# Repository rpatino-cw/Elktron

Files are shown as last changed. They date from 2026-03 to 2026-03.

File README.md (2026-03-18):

<div align="center">
  Elktron — Robotics for the data center floor
  <h1>Elktron</h1>
  <p><strong>A robotics platform for data center operations.</strong></p>
  <p>Demonstrated through an autonomous escort bot, a robot-arm training pipeline, and a live operations dashboard.</p>
  <p>
    
    
    
    
  </p>
  <p>
    <a href="https://rpatino-cw.github.io/Elktron/"><strong>Live Site</strong></a>
  </p>
</div>

<br/>

## The Problem

Data center technicians spend hours each shift on repetitive physical work — walking alongside vendors, watching them work, manually logging rack interactions, seating optics one-by-one. These tasks are mechanical and tie up skilled engineers who should be troubleshooting, turning up racks, and solving real problems. Elktron automates the floor work so DCTs can focus on what actually moves the needle.

---

## The Live Demo — Escort Bot

<div align="center">
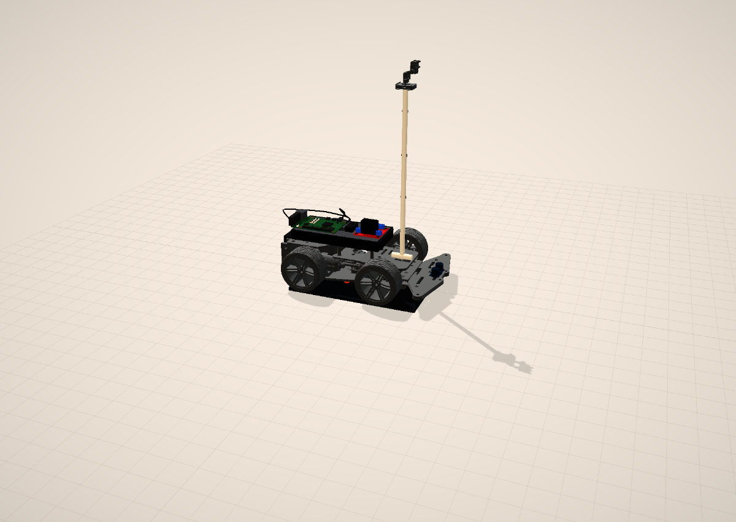
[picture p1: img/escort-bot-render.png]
Escort Bot — fully assembled with mast and pan-tilt camera

</div>

An autonomous 4WD robot that lives in the data hall. When a vendor enters, the bot detects them using real-time person detection, follows them through the aisles at a safe distance, and stops when they stop. If the vendor pauses at a rack, the bot runs an automated camera scan — sweeping bottom to top, capturing the state of every node before and after work is done.

No ROS. No cloud. A Raspberry Pi 5, a camera, and Python.

The tech checks in the vendor, assigns the bot, and goes back to real work.

<code>Raspberry Pi 5 · YOLOv8n · 4WD Chassis · PID Steering · Ultrasonic Obstacle Avoidance</code>

<a href="https://rpatino-cw.github.io/Elktron/escort-bot/assembly.html">

</a>
&nbsp;
<a href="https://rpatino-cw.github.io/Elktron/escort-bot/simulation.html">

</a>

---

## The Platform Extends — SO-101 Robot Arm

A robotic arm trained by demonstration to seat optics into switch ports. A technician shows the arm the task — pick up a transceiver, align it, insert it — and the arm learns to repeat the motion autonomously. No manual programming. You teach by showing.

Built on the HiWonder SO-ARM101 platform using Hugging Face's LeRobot framework. After ~50 demonstrations, the arm trains an ACT policy and runs on its own — same motion, same precision, no fatigue.

<code>SO-ARM101 · LeRobot · ACT Policy · 6-DOF Feetech Servos</code>

<a href="https://rpatino-cw.github.io/Elktron/robotics-site/so101/showcase.html">

</a>

---

## Unified Dashboard

Both robots feed into a single control panel — escort bot position, camera feeds, arm task progress, scan history. A tech sees at a glance what's running, what's done, and what needs attention without walking the floor.

<code>FastAPI · WebSocket · Vanilla JS</code>

---

## Why It's Reproducible

Every component comes with interactive 3D documentation — assembly instructions, wiring diagrams, a full DC floor simulation. The system is packaged not just as a demo, but as something another CoreWeave site could understand and build.

| Demo | What It Shows |
|---|---|
| [**3D Assembly Guide**](https://rpatino-cw.github.io/Elktron/escort-bot/assembly.html) | 15-step escort bot build with animated 3D models |
| [**Interactive Wiring**](https://rpatino-cw.github.io/Elktron/escort-bot/wiring-guide.html) | GPIO pin map — every connection between Pi, motor driver, sensors, and power |
| [**DC Floor Simulation**](https://rpatino-cw.github.io/Elktron/escort-bot/simulation.html) | 10-rack data hall with autonomous bot AI and collision detection |
| [**System Topology**](https://rpatino-cw.github.io/Elktron/robotics-site/topology.html) | How the escort bot, arm, and dashboard connect |

---

## Architecture

```mermaid
graph LR
    A["<b>Escort Bot</b><br/>Pi 5 · YOLOv8n · PID Steering"] -->|WebSocket| C["<b>Elktron Dashboard</b><br/>FastAPI · Vanilla JS"]
    B["<b>SO-101 Arm</b><br/>LeRobot · ACT Policy"] -->|Serial USB| C
    C -->|Live UI| D["Browser<br/>Status · Camera · Scan Logs"]
```

---

## Tech Stack

| Component | Stack |
|---|---|
| **Escort Bot** | Raspberry Pi 5 · YOLOv8n (Ultralytics) · picamera2 · gpiozero · lgpio · PID controller · Python 3.11 |
| **SO-101 Arm** | LeRobot (HuggingFace) · ACT policy · Feetech serial bus · PyTorch · Python |
| **Dashboard** | FastAPI · WebSocket · Vanilla JS · CSS Grid |

---

## Quick Start

**Escort Bot** (on Raspberry Pi 5 — Bookworm Lite 64-bit):
```bash
cd escort-bot && chmod +x install.sh && ./install.sh
python3 main.py              # Full escort + scan mode
python3 main.py --simulate   # Test without hardware
```

**SO-101 Arm** (Mac/Linux with CUDA, MPS, or CPU):
```bash
cd robotics-site/so101 && chmod +x install.sh && ./install.sh
python record.py     # Record demos via teleoperation
python train.py      # Train ACT policy
python deploy.py     # Deploy autonomous
```

---

## Build Progress

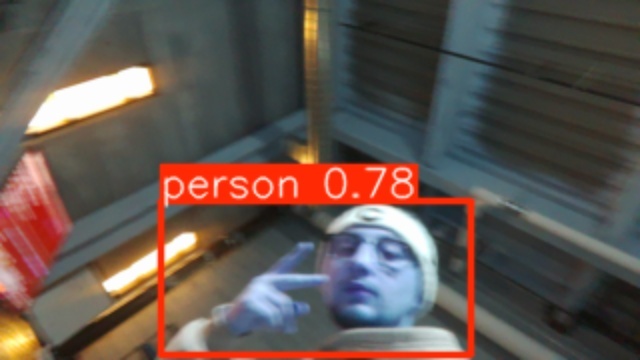
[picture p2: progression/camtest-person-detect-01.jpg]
YOLOv8n person detection running on Pi 5


> *YOLOv8n person detection confirmed at 78% confidence on the DC floor — March 16, 2026*

| Milestone | Status |
|---|---|
| Chassis assembled (LK-COKOINO 4WD) | Done |
| L298N motor driver wired to Pi 5 GPIO | Done |
| Arducam IMX708 wide-angle camera via CSI | Done |
| YOLOv8n person detection on Pi 5 | **Working** |
| Claude Code running on Pi 5 | Done |
| Motor control + PID tuning | Next |
| Full person-following integration | Next |
| SO-101 arm assembly + training | Next |

---

<details>
<summary><strong>Hardware Cost — $430 total</strong></summary>
<br/>

| Item | Cost | Status |
|---|---|---|
| LK-COKOINO 4WD Chassis | $25 | Assembled |
| L298N Motor Driver | $7 | Wired |
| Arducam IMX708 Wide-Angle | $60 | Connected |
| Arducam Pan-Tilt Platform | $27 | In hand |
| Raspberry Pi 5 (4GB) + Active Cooler | $70 | Running |
| HC-SR04 Ultrasonic Sensor | $9 | In hand |
| HiWonder SO-ARM101 | $270 | Ordered |
| Batteries + USB-C Power Bank | $48 | In hand |
| PVC Mast + Fittings | $15 | In hand |
| **Total** | **~$430** | |

</details>

<details>
<summary><strong>Repo Structure</strong></summary>
<br/>

```
hackathon/
├── escort-bot/              # Escort bot — brain, wiring, setup, 3D pages
│   ├── main.py              # Robot brain (373 lines — FOLLOW / SCAN / IDLE)
│   ├── pan_tilt.py           # Pan-tilt servo controller
│   ├── pid.py                # PID controller for steering
│   ├── assembly.html         # 3D assembly guide (Three.js)
│   ├── simulation.html       # DC floor simulation
│   ├── wiring-guide.html     # Interactive 3D wiring
│   ├── tests/                # Hardware test scripts
│   └── tools/                # Label printer, PDF generators
├── robotics-site/            # SO-101 arm — landing page + code
│   └── so101/                # record.py, train.py, deploy.py
├── elktron-app/              # Dashboard — FastAPI + WebSocket UI
│   └── api/server.py
├── glb/                      # 3D models (Meshy AI generated)
├── progression/              # Build progress photos
├── docs/                     # Checklists, parts list, team, philosophy
└── PROGRESS.md               # Single source of truth
```

</details>

<details>
<summary><strong>Demo Story (2:30)</strong></summary>
<br/>

1. **The Problem** (25s) — DC floor, repetitive tasks, skilled techs on autopilot
2. **Escort Bot** (75s) — Bot follows vendor through aisle, stops at rack, scans. Dashboard shows live tracking. "No ROS. No cloud. A Pi, a camera, and Python."
3. **Robot Arm** (35s) — Platform extends to optic seating. Trained by demonstration, runs autonomously. "You teach by showing."
4. **Close** (15s) — Dashboard unifies both systems. "Elktron — the data hall assistant. More. Better. Faster."

</details>

---

## Team

| Name | Role |
|---|---|
| **Romeo Patino** | Architecture, software, integration |
| **Alex Murillo** | Escort bot hardware, chassis, field testing |
| **Joshua Tapia** | SO-101 arm — CV, inverse kinematics, ACT training |
| **Parth Patel** | Dashboard backend, data integration |
| **Talha Shakil** | Demo video, pitch deck, media |
| **Raphael Rodea** | Build crew, logistics, demo day ops |

---

<div align="center">
<sub>Built in 7 days with $430 for CoreWeave "More. Better. Faster." 2026</sub>
<br/>
<sub><a href="docs/">Full documentation</a> · <a href="PROGRESS.md">Build progress</a> · <a href="https://rpatino-cw.github.io/Elktron/">Project Hub</a></sub>
</div>

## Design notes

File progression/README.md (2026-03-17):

# Progression — Build Evidence

Photos and screenshots documenting the Elktron escort bot build process at the DC floor.

---

## 2026-03-16 — Full Hardware Assembly + Person Detection Working

Major milestone: chassis assembled, L298N wired to Pi 5 GPIO, Arducam IMX708 connected via CSI ribbon, and **YOLOv8n person detection confirmed working on the DC floor** at 78% confidence. Claude Code installed directly on the Pi for on-device AI development.

### Hardware Assembly Photos

| File | What |
|---|---|
| `pi5-active-cooler-dc.jpg` | Pi 5 in red case with active cooler, powered at DC workbench (Cisco switch visible) |
| `pi5-camera-ribbon.jpg` | Pi 5 close-up showing CSI ribbon cable ("Standard - Mini 200mm") to Arducam IMX708 |
| `pi5-camera-dc-floor.jpg` | Pi 5 with camera connected, Cisco equipment in background |
| `chassis-wiring-overview.jpg` | Full bot: Pi 5 + LK-COKOINO 4WD chassis + L298N motor driver, all wired |
| `chassis-l298n-full.jpg` | Overhead view — chassis with L298N and motor wiring visible |
| `l298n-wiring-closeup.jpg` | L298N motor driver close-up — blue GPIO wires + red power to motors |
| `l298n-gpio-wires.jpg` | L298N with GPIO control wires (blue/green/black) and motor power (red) |
| `motor-wiring-detail.jpg` | Motor wiring detail — labeled motor connectors, L298N output terminals |

### Person Detection Test (on Pi 5 at DC)

| File | What |
|---|---|
| `camtest-person-detect-01.jpg` | Detection output — "person 0.78" bounding box on camera frame |
| `camtest-person-detect-03.jpg` | Second detection frame — same confidence, different pose |
| `camtest_01-05.jpg` | All 5 test frames with detection bounding boxes |
| `yolov8n-terminal-output.jpg` | Terminal: YOLOv8n loading, 5/5 frames captured, all detecting 1 person |
| `scp-transfer-pi.jpg` | SCP transfer of camtest images from Pi (elktron@192.168.3.57) to Mac |

### Technical Details
- **Model:** YOLOv8n (ultralytics)
- **Camera:** Arducam IMX708 wide-angle (libcamera v0.7.0+rpt20260205)
- **Resolution:** 640x360 sRGB + 1536x864 RAW
- **Confidence:** 0.78 (person class)
- **Pi hostname:** elktron@192.168.3.57
- **Location:** CoreWeave EVI01 DC floor
- **Claude Code:** Installed on Pi — on-device AI development confirmed
- **Chassis:** LK-COKOINO 4WD with yellow-tape motor labels (FR, FL, RR, RL)
- **Motor driver:** L298N (WWZMDiB) — GPIO control wires (blue) + motor power (red)
- **Power:** USB-C power bank visible in assembly photos

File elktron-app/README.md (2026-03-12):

# Elktron Dashboard

Real-time operations dashboard for the Elktron hackathon project — two DC floor robots controlled and monitored from a single interface.

## The Problem

DCTs manage robot arms and escort bots manually. There's no unified view of what the arm is doing, what the escort bot scanned, or whether a vendor touched something they shouldn't have. This dashboard is the control center.

## What It Does

- **Live arm status** — see joint angles, gripper state, and current task in real time
- **Escort monitoring** — watch the bot escort a vendor, scan a rack, and flag unauthorized contact
- **Scan history** — every vendor escort produces a JSON report. Browse, filter, drill in.
- **Training controls** — start/stop teleoperation recording, kick off cloud training, download models
- **Camera feeds** — live USB webcam streams from the arm wrist and escort bot

## Demo Story

1. **Arm demo** — open dashboard, show arm status "READY". Start teleoperation. Move arm to pick optic. Show joint angles updating live. Stop recording. Kick off training.
2. **Escort demo** — vendor arrives. Dashboard shows "Escorting to CAB-B3". Bot arrives, baseline scan runs. Vendor works on RU-24. Dashboard shows live node status. RU-25 gets a brief contact — amber alert, then clears. Work completes. Scan report saved.
3. **Review demo** — open scan log. Show 3 past scans: 2 clean, 1 flagged. Drill into the flagged one — unauthorized contact on RU-19 that didn't resolve.

## Tech Stack

- **Frontend:** HTML + vanilla JS + CSS Grid. WebSocket for live data.
- **Backend:** Python FastAPI. WebSocket bridge to hardware.
- **Hardware:** LeRobot (arm), ROS2 or GPIO (escort bot), USB webcams.

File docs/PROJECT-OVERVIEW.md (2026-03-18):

# Elktron — Project Overview

## What It Is

Elktron is a robotics platform for the data center floor. It automates repetitive physical work — escorting vendors, scanning racks, seating optics — so DCTs can spend their time on troubleshooting, rack turn-ups, and the problems that actually need a human.

The live proof point is the **Escort Bot**: an autonomous robot that detects a person, follows them through the data hall, and scans racks when they stop. The platform extends to a **robot arm** that learns optic seating by demonstration, and a **dashboard** that unifies both systems with live telemetry and control.

## The Problem

At a site like EVI01, technicians spend hours each shift on autopilot work:

- **Vendor escorts** — every visit requires a tech to physically shadow the vendor, 30 minutes to 2 hours each time
- **Optic seating** — inserting transceivers one by one, 5-10 minutes per module, hundreds of ports per rack turn-up
- **Rack inspections** — manual visual checks that could be captured and logged automatically

These tasks don't require engineering skill. They require presence. Elktron provides that presence.

## The Escort Bot

An autonomous 4WD robot that lives in the data hall. When a vendor enters, the bot detects them using real-time person detection (YOLOv8n on a Raspberry Pi 5), follows them through the aisles at a safe distance, and responds to their movement:

- **FOLLOW mode** — tracks the person, maintains target distance using dual PID controllers, steers using differential (tank-style) drive
- **SCAN mode** — when the person stops at a rack for ~3 seconds, the bot assumes work is happening and runs an automated camera sweep, capturing the state of every node from bottom to top
- **IDLE mode** — robot waits patiently until a person reappears

An ultrasonic sensor provides obstacle avoidance at 30cm, because a robot blindly following someone into a rack is how you create an incident report.

The tech checks in the vendor, assigns the bot, and goes back to real work.

**Stack:** Raspberry Pi 5, Arducam IMX708 wide-angle camera, LK-COKOINO 4WD chassis, L298N motor driver, HC-SR04 ultrasonic sensor, gpiozero + Python. No ROS. No cloud.

## The SO-101 Robot Arm

A robotic arm trained by demonstration to seat fiber optic transceivers into switch ports. A technician shows the arm the task — pick up a transceiver, align it, insert it — and the arm learns to repeat the motion autonomously. No manual programming. You teach by showing.

Built on the HiWonder SO-ARM101 (6-DOF, Feetech servos) using Hugging Face's LeRobot framework. After ~50 demonstrations recorded via leader-follower teleoperation, the system trains an ACT (Action Chunking Transformers) policy that generalizes the motion.

The arm represents where the platform goes next — every repetitive physical task on the DC floor is a candidate for this approach.

## The Dashboard

A unified control panel that ties the system together. Five panels: escort bot position and camera feed, arm task progress and joint angles, scan history with before/after images, training metrics, and system health.

Built on FastAPI with WebSocket for real-time telemetry. Designed with mock-data fallback so the dashboard demonstrates the full experience even when hardware isn't connected, then swaps to real data seamlessly when it is.

## Why It's Reproducible

Every component comes with interactive 3D documentation — step-by-step assembly instructions, GPIO wiring diagrams, and a full DC floor simulation. The system is packaged not just as a demo, but as something another CoreWeave site could understand and build.

Key resources:
- **3D Assembly Guide** — 15-step escort bot build with animated Three.js models
- **Interactive Wiring** — every connection between the Pi, motor driver, sensors, and power
- **DC Floor Simulation** — 10-rack data hall with autonomous bot AI
- **System Topology** — how all components connect

## The Stack

| Layer | Technology |
|---|---|
| Compute | Raspberry Pi 5 (4GB, Bookworm 64-bit) |
| Vision | YOLOv8n (Ultralytics), Arducam IMX708 via libcamera |
| Motor control | gpiozero + L298N via GPIO |
| Steering | Custom dual PID (lateral centering + distance tracking) |
| Arm framework | LeRobot (Hugging Face) + ACT policy |
| Arm hardware | HiWonder SO-ARM101, Feetech STS3215 servos |
| Backend | FastAPI + WebSocket + Pydantic |
| Frontend | Vanilla JS — no frameworks |
| 3D documentation | Three.js (v0.162.0–v0.170.0) |
| Remote access | Tailscale |
| On-device dev | Claude Code running directly on the Pi |

## The Team

Six CoreWeave DCTs from Elk Grove:

| Name | Role |
|---|---|
| **Romeo Patino** | Lead — architecture, software, integration, daily comms |
| **Joshua Tapia** | SO-101 arm — assembly, calibration, ACT training |
| **Alex Murillo** | Escort bot hardware — chassis, wiring, field testing |
| **Parth Patel** | Dashboard backend — FastAPI, data integration |
| **Talha Shakil** | Media — demo video, pitch deck, logo |
| **Raphael Rodea** | Build crew — assembly, labels, logistics, demo day ops |

## The Pitch (One Paragraph)

Elktron is the data hall assistant. An autonomous escort bot follows vendors through the DC, scans racks when they stop, and feeds everything to a live dashboard. The platform extends to a robot arm that learns optic seating by demonstration — same dashboard, same telemetry, same unified control. Every component is documented with interactive 3D guides so another site can reproduce it. Built in 7 days by DCTs, for DCTs, with $430 in off-the-shelf parts. Elktron doesn't replace technicians. It gives them back their time.

## Budget

Total: **~$430** for both robots, all parts, off-the-shelf. No custom fabrication.

---

*CoreWeave "More. Better. Faster." Hackathon — March 23–25, 2026 · Demo Day: March 26*
*Track: Build with Velocity*

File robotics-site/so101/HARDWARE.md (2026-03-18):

# Elktron SO-101 — Hardware Guide

## What to Buy

### Option A: HiWonder Kit (easiest)
| Item | Price | Link |
|---|---|---|
| SO-ARM101 DIY Kit (both arms, all servos, boards, power, clamps) | $270 | [hiwonder.com/products/lerobot-so-101](https://www.hiwonder.com/products/lerobot-so-101) |
| USB webcam (1080p) | $20-30 | Any OpenCV-compatible |
| **Total** | **~$300** | |

### Option B: Seeed Studio + 3D Print (cheaper)
| Item | Price |
|---|---|
| Servo motor kit (12x STS3215 servos + boards) | $220 |
| 3D-printed parts (order from JLCPCB/PCBWay or self-print) | $35 |
| USB webcam | $20-30 |
| **Total** | **~$275** | |

### Already Have
- Raspberry Pi 5 (or laptop for training)
- USB-C cables (2x, included in kit)

## Kit Contents (HiWonder DIY)
- 1x Follower arm: 6x HX-30HM bus servos (STS3215, 30kg.cm torque)
- 1x Leader arm: 6x HX-10HM bus servos (STS3215, lighter gearing)
- 2x BusLinker V3.0 servo controller boards
- 1x 12V 5A power supply (follower)
- 1x 5V power supply (leader)
- 4x table clamps
- All 3D-printed structural parts
- Screws, cables, assembly tools

## Assembly Notes
- DIY kit: ~2-3 hours to assemble both arms
- Follow HiWonder's assembly video or [TheRobotStudio GitHub](https://github.com/TheRobotStudio/SO-ARM100) for STLs and build guide
- Clamp both arms to the same table, ~30cm apart
- Camera mounts above or to the side of the follower workspace

## Connections

```
Laptop/Pi 5
  ├── USB-C → BusLinker (Leader arm)
  ├── USB-C → BusLinker (Follower arm)
  └── USB   → Webcam

12V 5A PSU → Follower arm power
5V PSU     → Leader arm power
```

## Compute Options for Training

| Machine | Device flag | Training time (50 episodes) |
|---|---|---|
| Mac M1/M2/M3 | `--device mps` | ~2-4 hours |
| NVIDIA GPU (RTX 3060+) | `--device cuda` | ~1-2 hours |
| Google Colab (free T4) | `--device cuda` | ~3-5 hours |
| Raspberry Pi 5 (CPU) | `--device cpu` | Not recommended for training |

**Hackathon strategy:** Record on Pi/laptop → train on Mac or Colab → deploy on Pi.

## Demo Day Setup

For the Demo Day (March 26) demo, you need:
1. Follower arm clamped to table
2. Optic + transceiver cage in workspace
3. Pi 5 or laptop running `deploy.py`
4. Camera showing the arm's view on a monitor (impressive for audience)

Keep the leader arm connected but out of the way — useful for live teleoperation fallback if the trained policy struggles.

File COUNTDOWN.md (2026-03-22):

# Elktron — Countdown to Demo Day

**Last updated:** 2026-03-21 (update every morning)

---

## Hard Rules

1. **Escort bot (RC) done by Monday 3/24.** No exceptions. This is the star of the demo.
2. **ARM GO/NO-GO: Monday 3/24 end of day.** If it's not assembled, calibrated, and running a basic teleop — cut it from the demo. One perfect robot > two broken robots.
3. **Feature freeze: Tuesday 3/25 noon.** After that, only bug fixes, video recording, and polish.
4. **Romeo does not push code while Josh/Parth are working onsite.** They own the repo during their sessions.

---

## Day-by-Day

### Friday 3/21 — Integration Sprint

| Task | Owner | Status |
|---|---|---|
| Pull latest repo on Pi | Josh | [x] Done |
| Dashboard running on Josh's laptop | Josh, Parth | [ ] |
| Set Pi IP in `escort.py` line 36, test connectivity | Josh | [ ] |
| Camera feed streaming Pi → dashboard | Josh | [ ] |
| Xbox controller teleoperation — bot drives | Josh | [ ] |
| YOLOv8n detection running on Pi camera | Josh, Parth | [ ] |
| Fix L298N 5V logic pin if not done | Josh, Parth | [ ] |
| Demo script review (remote) | Romeo | [ ] |
| Pitch deck polish (remote) | Romeo | [ ] |

**End-of-day check:** Can the bot drive via controller and stream camera to dashboard?

---

### Saturday 3/22 — Arm Print + Bot Tuning

| Task | Owner | Status |
|---|---|---|
| 3D print SO-101 arm parts (overnight print OK) | Josh | [ ] |
| PID tuning — smoother person following | Josh, Parth | [ ] |
| Ultrasonic sensor wired + tested | Josh, Parth | [ ] |
| PVC mast + camera elevation mounted | Onsite crew | [ ] |
| Wire cleanup — velcro, zip ties, clean routing | Onsite crew | [ ] |
| Dashboard polish — Drive & Detection panel | Romeo (remote) | [ ] |
| Repo README cleanup for judges | Romeo | [ ] |

**End-of-day check:** Bot follows a person smoothly. Arm parts printing.

---

### Sunday 3/23 — Hackathon Day 1: Bot Complete + Arm Assembly

| Task | Owner | Status |
|---|---|---|
| Escort bot end-to-end: follow + scan + dashboard | Josh, Parth | [ ] |
| Record phone video of bot following person | Anyone onsite | [ ] |
| Assemble SO-101 arm (3D-printed parts ready) | Josh | [ ] |
| Install LeRobot, calibrate servos | Josh | [ ] |
| First arm teleop test | Josh | [ ] |
| Coordinate with Talha on filming plan | Romeo | [ ] |

**End-of-day check:** Bot demo-ready. Arm assembled and servos responding.

---

### Monday 3/24 — Hackathon Day 2: ARM GO/NO-GO

| Task | Owner | Status |
|---|---|---|
| Arm basic teleop working? | Josh | [ ] |
| **GO/NO-GO DECISION (end of day):** | Team | [ ] |
| → GO: Record 50 optic seating demos, start ACT training | Josh | [ ] |
| → NO-GO: Cut arm from demo, double down on escort bot | Team | [ ] |
| Escort bot floor test — real DC aisle | Onsite crew | [ ] |
| Escort bot scan mode — camera sweeps rack | Onsite crew | [ ] |
| Dashboard with live data — ready for screen recording | Josh | [ ] |
| B-roll filming — bot on floor, wiring, Pi boot | Talha, Raphael | [ ] |

**End-of-day check:** Arm decision locked. Escort bot runs clean on DC floor.

---

### Tuesday 3/25 — Hackathon Day 3: FEATURE FREEZE + VIDEO

**NOON: FEATURE FREEZE. No new code after this.**

| Task | Owner | Status |
|---|---|---|
| Morning: final bug fixes only | Josh, Parth | [ ] |
| NOON: Feature freeze — lock it down | Team | [ ] |
| Record demo video (2:30 target) | Talha + team | [ ] |
| Screen-record dashboard walkthrough | Romeo or Josh | [ ] |
| Record voiceover (separate track) | Romeo | [ ] |
| Edit video — footage + VO + music | Talha | [ ] |
| If arm GO: record arm demo footage | Josh | [ ] |
| Slides/pitch deck finalized | Romeo, Talha | [ ] |
| GitHub repo — clean README, screenshots, links | Romeo | [ ] |
| Submit video + repo + slides | Talha | [ ] |

**End-of-day check:** Video submitted. Repo pushed. Slides done.

---

### Wednesday 3/26 — DEMO DAY (11am-2pm PT / 2pm-5pm ET)

| Task | Owner | Time |
|---|---|---|
| Pack hardware — bot, arm (if GO), power banks, cables, laptop | Raphael | Morning |
| Set up demo table — bot on display, dashboard on screen | Team | 10:30am PT |
| Test live demo — bot drives, dashboard streams | Josh | 10:45am PT |
| Charge all batteries | Raphael | Night before |
| Presentations begin | Team | 11:00am PT |
| Raphael plays "vendor" during live demo | Raphael | During demo |

---

## Talha's Deliverables — Media & Presentation Timeline

| Deadline | Deliverable | Notes |
|---|---|---|
| **Sun 3/23** | Filming plan finalized | Coordinate with Romeo on shot list (`docs/DEMO-SCRIPT.md`) |
| **Mon 3/24** | B-roll filmed | Bot on DC floor, wiring close-ups, Pi boot, terminal output, team working |
| **Mon 3/24 EOD** | Logo + team signage ready | Printed for demo table |
| **Tue 3/25 morning** | All live robot footage filmed | Bot following person, scan mode, arm demo (if GO) |
| **Tue 3/25 noon** | Screen recordings done | Dashboard walkthrough, training pipeline (if arm GO) |
| **Tue 3/25 afternoon** | Voiceover recorded | Romeo records VO, Talha receives audio track |
| **Tue 3/25 evening** | Video edited + exported | 2:30 target, footage + VO + music layered |
| **Tue 3/25 night** | Slides finalized | With Romeo — 5-7 slides max |
| **Tue 3/25 EOD** | **SUBMIT: video + repo + slides** | Final deliverable — non-negotiable deadline |

**Talha needs from the team:**
- Shot list approval by Sunday (Romeo)
- Working robot on DC floor by Monday (Josh)
- Dashboard running live by Monday (Josh)
- Voiceover audio by Tuesday noon (Romeo)
- Arm GO/NO-GO by Monday EOD (determines what to film Tuesday)

---

## Giving Talha Filmable Moments

Talha can't edit what doesn't exist. The team's #1 job Monday is creating footage, not writing code.

**What Talha needs filmed (and who makes it happen):**

| Footage | Who Sets It Up | When | Notes |
|---|---|---|---|
| Bot following a person through DC aisle (wide shot) | Josh drives bot, Raphael walks as "vendor" | Mon 3/24 | THE hero shot. Get 3-4 takes minimum. |
| Bot stop/start behavior — vendor stops, bot stops | Same setup | Mon 3/24 | Shows intelligence, not just driving |
| Bot scan mode — camera sweeps rack | Josh triggers scan | Mon 3/24 | Slow, dramatic tilt. Talha films from side. |
| Close-up: Pi 5 + camera on mast, chassis rolling | Anyone | Mon 3/24 | B-roll. Show the hardware. |
| Dashboard with live data on laptop screen | Josh has dashboard running | Mon 3/24 | Screen-record AND film the laptop from over-shoulder |
| Arm optic seating (if GO) | Josh demos arm | Tue 3/25 morning | Even 1 successful grab is enough |
| Arm training — leader-follower teleop | Josh | Tue 3/25 morning | Shows "teach by demonstration" |
| Team working — wiring, terminal, debugging | Anyone | Mon 3/24 | Candid B-roll. Shows builder energy. |
| DC environment — racks, aisles, cables | Anyone with phone | Mon 3/24 | Sets the scene. 5-10 seconds is enough. |
| Pi boot sequence — terminal scrolling | Anyone | Anytime | Cool visual for transitions |

**How to make this happen:**
1. **Sunday:** Romeo coordinates with Talha on shot list above. Talha confirms he has a phone/camera ready.
2. **Monday morning:** Josh gets bot driving + dashboard live. This is Talha's filming window.
3. **Monday midday:** Talha films all bot footage (30-45 min dedicated filming session). Josh and Raphael support.
4. **Monday afternoon:** Talha films B-roll (team working, DC environment, hardware close-ups).
5. **Tuesday morning:** If arm is GO, Talha films arm footage. If NO-GO, skip — Talha starts editing.
6. **Tuesday noon:** Romeo records voiceover. Sends audio to Talha.
7. **Tuesday afternoon-evening:** Talha edits. Team reviews. Final export.

**Rule:** Monday is filming day, not coding day. If something isn't working by Monday morning, don't spend all day debugging — film what IS working and move on.

---

## Fallback: Single-Robot Demo (if arm is cut)

The demo becomes 100% escort bot:
- **More screen time** for bot following + scanning
- **Dashboard** shows escort tracking, camera feeds, scan logs (arm panel shows "Coming Soon" or mock data)
- **Narration** mentions the arm as "next phase" — pipeline is built, just needs hardware time
- **Demo script adjustment:** expand bot section from 1:15 to 1:45, shrink arm section to a 15s "what's next" teaser
- Reference `docs/DEMO-SCRIPT.md` → Fallback Strategies section

---

## Demo Day Packing Checklist

- [ ] Escort bot (fully assembled, clean wiring)
- [ ] SO-101 arm (if GO)
- [ ] Raspberry Pi 5 + power bank + USB-C cable
- [ ] Laptop (dashboard ready to run)
- [ ] Xbox controller
- [ ] Phone for backup filming
- [ ] Extension cord / power strip
- [ ] Spare 18650 batteries (charged)
- [ ] Spare USB-C power bank
- [ ] Printed team name card / signage

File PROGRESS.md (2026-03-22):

# Elktron — Progress Log

## Project Overview
**Two robots for the CoreWeave Hackathon (March 23–25, 2026 · Demo Day: March 26)**
1. **SO-101 Arm** — Imitation learning for DC tasks (optic seating)
2. **Escort Bot** — Person-following vendor escort on the DC floor

---

## Current Status

| Robot | Code | Hardware | Tested | Demo Ready |
|---|---|---|---|---|
| SO-101 Arm | Done | **Ordered 3/9** — ETA ~3/18 | No | No |
| Escort Bot | Done | **Assembled 3/16** — chassis built, L298N wired, camera connected | **YES — person detection working** | In progress |

## Slack Checklist — 10 Steps to Demo Day

Tracked in `#the-elks-2026` Slack list.

| Phase | Task | Status | Assignee | Due |
|---|---|---|---|-----|
| 1 | Sign up + admin — register team, share repo, confirm availability | **Done** | Josh | 3/12 |
| 2 | Receive + inventory hardware — open packages, verify, label, organize | **Done** | Alex, Romeo | 3/13 |
| 3 | Flash Pi + install software — Bookworm Lite, deps, YOLOv8n model | **Done** | Romeo | 3/14 |
| 4 | Build escort bot — assemble chassis, wire L298N, build mast, mount camera | **~80% done** — chassis + L298N + camera done, mast + HC-SR04 + motor power remaining | Alex, Raphael | 3/16 |
| 5 | Test escort bot — person detection, floor test, tune steering and speed | **In progress** — detection working, motors blocked (L298N 5V fix needed) | Romeo, Alex | 3/18 |
| 6 | Build SO-101 arm — assemble, calibrate, install LeRobot | Not started — kit ETA 3/18 | Josh | 3/19 |
| 7 | Train arm — record 50 demos, train ACT policy | Not started | Josh | 3/21 |
| 8 | Dashboard integration — live feeds, telemetry, scan log | **In progress 3/21** — code built by Romeo, Josh + Parth onsite testing/integrating | Josh, Parth | 3/21 |
| 9 | Demo polish — clean wiring, signage, rehearse | Not started | Talha, Raphael | 3/22 |
| 10 | Record + submit — 2-3 min video, slides, GitHub | Not started | Talha | 3/25 |

## Team (6 active + 1 observer)

| Person | Role | Owns |
|---|---|---|
| **Romeo Patino** | Lead — architecture, software, demo story | System design, escort bot software, dashboard frontend, Pi setup |
| **Joshua Tapia** | Integration lead + robot arm | Dashboard/API integration, Xbox teleoperation, YOLOv8n+PID, SO-101 arm |
| **Alex Murillo** | Escort bot hardware lead | Chassis build, wiring, motor/sensor integration, floor testing |
| **Parth Patel** | Pi setup + integration support | Pi CLI/terminal setup (powerlevel10k, tools), onsite integration testing with Josh |
| **Talha Shakil** | Media & presentations | Demo video, pitch deck, logo, filming, editing |
| **Raphael Rodea** | Build crew + logistics | Assembly, parts inventory, batteries, wiring checks, packing, demo day "vendor" |
| **Andrew Westberg** | Observer | Watching and learning — not on active roster |

---

## What's Been Done

### Session: 2026-03-21

**Josh + Parth Onsite — Integration Sprint**
- Josh and Parth onsite at DC, Romeo remote
- Josh pulled latest repo on Pi
- **Clarification:** Romeo built all the code (api_server.py, dashboard, main.py, etc.). Parth's contributions so far: Pi terminal/CLI setup (powerlevel10k, shell tools) — has not written project code
- Josh's plan (from Slack):
  1. Get dashboard working on his laptop
  2. Simple Xbox controller teleoperation
  3. Switch to YOLOv8n + PID person following
- Josh is good with the API stuff — owns integration
- Parth supporting Josh onsite
- Romeo confirmed: code is scaffolded but untested on real hardware — full freedom to refactor if needed
- Romeo not pushing today — Josh + Parth own the repo, pushing via Claude on Pi
- `api_server.py` (Pi Flask server) and `elktron-app/` (dashboard) are code-complete — integration/testing phase now
- Only config change needed: set Pi IP in `elktron-app/api/escort.py` line 36

### Session: 2026-03-18

**Parth Assigned to Dashboard Backend**
- Parth confirmed in `#the-elks-2026` — taking on the camera system / dashboard backend for both bots
- Dashboard frontend is done (5 panels, mock data). Backend skeleton exists (FastAPI + WebSocket + Pydantic models)
- Critical gaps identified: Pi has no API server, no camera stream pipeline
- Parth needs to build `escort-bot/api_server.py` (Flask or FastAPI on Pi) + MJPEG camera stream
- Needs to coordinate with Josh on arm endpoints/data

**Site Audit & Cleanup**
- Deleted 25 broken/redundant HTML pages (43 → 18 live pages)
- Rebuilt `index.html` hub from 10 phases/37 cards → 5 phases/15 cards
- Fixed broken links in `robotics-site/index.html` and `mast-hardware.html`
- Updated `docs/hackathon-sites.md`, all CLAUDE.md files, Slack channel refs across 8 files
- Two commits pushed: `d677902` (cleanup) and `2b585cd` (audit)

### Session: 2026-03-17

**Pi 5 Environment Setup — Desktop + Remote Access**
- Desktop environment + CLI tools + GUI apps installed on Pi 5
- Python venv confirmed: torch, YOLOv8, picamera2, pillow all working
- Tailscale VPN up — Pi reachable remotely at `100.85.225.68` (ask Romeo for access)
- Wiring guide completed through Step 6

**Motor Blocker Identified**
- GPIO signals verified (`test_motors.py` → signal active: YES)
- **Root cause:** L298N +5V logic pin not connected → outputs stuck at 0V
- **Fix:** Connect Pi 5V → L298N +5V (remove regulator jumper first)
- L298N wiring diagram identified — specific pin connection was missed during assembly

**Hardware Updates**
- Bought 3ft ribbon cable for camera (longer reach for mast mounting)
- HC-SR04 voltage divider requirement confirmed: ECHO outputs 5V, Pi GPIO is 3.3V only — need 100Ω + 200Ω resistors on breadboard (must fit somewhere on chassis)
- Pi 5 needs airflow underneath — thermal management note for chassis design

**GitHub Repo Cleanup**
- Removed junk files, tightened structure, fixed README links

---

### Session: 2026-03-16

**MAJOR MILESTONE: Escort Bot Hardware Assembled + Person Detection Working on DC Floor**

**Hardware Assembly (at DC — EVI01)**
- LK-COKOINO 4WD chassis fully assembled — all 4 motors mounted, wheels attached, yellow tape labels (FR, FL, RR, RL)
- L298N motor driver (WWZMDiB) wired to Pi 5 GPIO — blue control wires for direction, red power wires to motor terminals
- Arducam IMX708 wide-angle camera connected via CSI ribbon cable ("Standard - Mini 200mm")
- Pi 5 in red case with official active cooler — running off USB-C power bank
- All assembly done at the DC workbench (Cisco switches visible in photos)

**Person Detection Test — SUCCESS**
- Ran `python3 /home/elktron/escort-bot/camtest.py` on Pi 5
- YOLOv8n model loaded and detecting persons at **0.78 confidence**
- Camera: libcamera v0.7.0+rpt20260205, IMX708 wide, 640x360 sRGB + 1536x864 RAW
- 5/5 frames captured, all detecting 1 person with bounding boxes
- SCP'd test images from Pi (elktron@192.168.3.57) to Mac for review

**Claude Code on Pi**
- Claude Code installed and running directly on the Pi 5
- On-device AI development confirmed — can iterate on detection code without leaving the DC

**Build Evidence**
- 26 photos captured — assembly process, wiring details, detection output
- All photos in `progression/` folder with descriptive filenames
- Terminal screenshots showing YOLOv8n output and SCP transfers

---

### Session: 2026-03-10

**Team Formed**
- Alex Murillo — ordering LK-COKOINO 4WD chassis kit (same one Romeo found), using her own Pi. ETA tomorrow (3/11).
- Josh Tapia — wrote robot arm technical breakdown: Computer Vision → Inverse Kinematics → End Effector → Optic Ammo. Scoped to one switch, one optic.
- Romeo — recommended LeRobot imitation learning to collapse Josh's CV + IK layers into one step (teach by demonstration instead of coding each separately). End effector identified as critical risk.

**Escort Bot Redesign**
- Bot needs to be **tall** — must scan full 42U rack top to bottom while escorting vendors
- Added pan/tilt servo for camera vertical sweep
- Switching from Freenove 4WD to LK-COKOINO chassis (Alex ordering) + separate Arducam camera + pan/tilt platform
- Differential (tank) steering confirmed over 4-wheel steering — simpler, more stable for a tall bot in straight DC aisles
- Mast needed: ~3-4 ft PVC pipe mounted on chassis to raise camera to mid-rack height

**Revised Hardware — Escort Bot**
- See updated shopping list below (3 stores: Amazon, Home Depot, Best Buy)

---

### Session: 2026-03-09 (late night)

**Parts List Finalized + Verified**
- Created `PARTS-LIST.md` — detailed BOM with Amazon links, checkboxes, wiring diagrams, cost summary
- Verified Freenove 4WD kit (FNK0043) includes: integrated motor driver (Smart Car Board PCB), HC-SR04 ultrasonic + servo mount, Pi Camera (CSI), 2x servos for pan-tilt, IR line tracking, LEDs, buzzer
- Confirmed: L298N, HC-SR04P, USB webcam, camera mount are NOT needed separately — all in Freenove kit
- Savings: ~$37 off original estimate
- Added Raspberry Pi 5 Official Active Cooler (~$5) — REQUIRED to prevent thermal throttle under TFLite CV workload

**Pi 5 Setup Guide**
- Created `escort-bot/PI-SETUP.md` — complete SD flashing + first boot + software setup guide
- **OS choice: Raspberry Pi OS Lite (64-bit) — Bookworm** — only OS that supports Pi 5, 64-bit for TFLite perf, Lite for headless (saves ~500MB RAM), ships Python 3.11 + lgpio
- Covers: Imager download, pre-configured WiFi/SSH, first boot, install.sh, verification tests, troubleshooting, demo-day perf tips

**Updated Cost**
- Escort bot: ~$145 (down from ~$177 after removing kit duplicates + adding cooler)
- SO-101 arm: ~$311
- Shared/demo: ~$17-47
- Grand total: ~$468-498

---

### Session: 2026-03-09 (evening)

**Hardware Ordered**
- Freenove 4WD Smart Car Kit — Amazon — ETA 3/11
- Samsung 30Q 18650 batteries + charger — Amazon — ETA 3/11
- MakerFocus Pi Battery Pack 10000mAh — Amazon — ETA 3/11
- HiWonder LeRobot SO-ARM101 Kit — hiwonder.com — **ETA ~3/18 (long pole)**
- NexiGo N60 1080P Webcam — Amazon — ETA 3/11
- Total: ~$408

**Camera-Only Test Script**
- Created `escort-bot/test_camera.py` — runs person detection without motors or ultrasonic
- Two modes: headless (terminal only) and `--display` (live video with bounding boxes)
- Simulates steering output so you can validate detection + steering logic before chassis arrives
- Run: `python3 test_camera.py` (headless) or `python3 test_camera.py --display` (with video)

---

### Session: 2026-03-09

**Research**
- Found iRobot Create 3 repos (decided against — overkill for this use case)
- Evaluated chassis options: Freenove 4WD ($65), SunFounder PiCar-X ($82), Yahboom ($70)
- Chose Freenove 4WD as escort bot platform
- Evaluated detection approaches: MobileNet SSD v2 (TFLite) wins at ~20 FPS on Pi 5
- Decided to skip ROS 2 — too heavy for a single-Pi demo, gpiozero is enough
- Researched SO-101 arm: HiWonder kits ($270-$460), LeRobot framework, ACT policy
- Found forkable repos: mshakeelt/Human-Following-Robot, LeRobot hackathon repo

**Escort Bot — Scaffolded**
- `hackathon/escort-bot/main.py` — Full person-following logic (~150 lines). TFLite MobileNet SSD + gpiozero + HC-SR04 ultrasonic. Proportional steering with distance control.
- `hackathon/escort-bot/install.sh` — One-command Pi 5 setup (apt + pip + model download)
- `hackathon/escort-bot/requirements.txt` — picamera2, opencv-python, gpiozero, numpy, lgpio
- `hackathon/escort-bot/WIRING.md` — GPIO pin map, L298N wiring, HC-SR04 voltage divider, test commands
- `hackathon/escort-bot/showcase.html` — Project scope page (white/navy theme, animations, 3D)

**SO-101 Arm — Scaffolded**
- `hackathon/robotics-site/so101/record.py` — Record demos via leader-follower teleoperation. 3 tasks defined: optic_seating (50 eps), rack_inspection (30), cable_management (100).
- `hackathon/robotics-site/so101/train.py` — Train ACT policy. Supports cuda/mps/cpu.
- `hackathon/robotics-site/so101/deploy.py` — Deploy trained model for autonomous execution.
- `hackathon/robotics-site/so101/install.sh` — venv + LeRobot from source + deps
- `hackathon/robotics-site/so101/requirements.txt` — lerobot, torch, opencv, numpy, tensorboard
- `hackathon/robotics-site/so101/HARDWARE.md` — BOM, assembly notes, kit tiers, compute options
- `hackathon/robotics-site/so101/showcase.html` — Project scope page (white/navy, 3D image, animations)

**Config Updates**
- Updated `hackathon/CLAUDE.md` — registered escort-bot, updated focus check to show both robots
- Updated `memory/MEMORY.md` — Elktron = two robots, Pi 4/5 as escort platform

---

## Hardware Shopping List

### Escort Bot — REVISED 2026-03-10

**Amazon**
| Item | Price | Who Orders | ETA | Link |
|---|---|---|-----|---|
| LK-COKOINO 4WD Chassis Kit | ~$25 | **Alex Murillo** | 3/11 | [Amazon](https://www.amazon.com/Arduino-LK-COKOINO-Raspberry-Building/dp/B0B5JPJ9R4) |
| Arducam 120° Wide Autofocus Camera (IMX708) | $59.99 | Romeo | **Ordered 3/10** — ETA 3/14 | [Amazon](https://www.amazon.com/Arducam-Raspberry-Camera-Autofocus-Acrylic/dp/B0BX7VFT8Q) |
| Arducam Pan Tilt Platform (2 servos + controller) | $26.99 | Romeo | **Ordered 3/10** — ETA 3/12 | [Amazon](https://www.amazon.com/Arducam-Upgraded-Camera-Platform-Raspberry/dp/B08PK9N9T4) |
| Pi 5 Active Cooler (Official) | $9.98 | Romeo | **Ordered 3/10** — ETA 3/11 | [Amazon](https://www.amazon.com/Raspberry-Pi-Active-Cooler/dp/B0CLXZBR5P) |
| WWZMDiB L298N Motor Driver 2-Pack | $6.98 | Romeo | **Ordered 3/10** — ETA 3/12 | [Amazon](https://www.amazon.com/WWZMDiB-L298N-H-Bridge-Controller-Raspberry/dp/B0CR6BX5QL) |
| ELEGOO HC-SR04 Ultrasonic 5-Pack | $8.99 | Romeo | **Ordered 3/10** — ETA 3/12 | [Amazon](https://www.amazon.com/ELEGOO-HC-SR04-Ultrasonic-Distance-MEGA2560/dp/B01COSN7O6) |
| DIYables HC-SR04 Ultrasonic 2-Pack | $6.99 | Romeo | **Ordered 3/10** — ETA 3/12 | [Amazon](https://www.amazon.com/Ultrasonic-Sensor-Arduino-ESP8266-Raspberry/dp/B0CKS867QC) |
| QTEATAK 18650 Battery Holder 8-Pack | $9.99 | Romeo | **Ordered 3/10** — ETA 3/12 | [Amazon](https://www.amazon.com/QTEATAK-18650-Battery-Holder-Bundle/dp/B08B86KHB2) |

**Home Depot (in-store pickup)**
| Item | Price | Link |
|---|---|---|
| PVC Pipe 1" Schedule 40 (cut to ~4 ft for mast) | ~$5 | [Home Depot](https://www.homedepot.com/b/Plumbing-Pipe-Fittings-Pipe-PVC-Pipe/N-5yc1vZ1z18i41) |
| PVC T-connector (mount mast to chassis) | ~$2 | In-store |
| Velcro cable ties / strips (reusable) | ~$5 | Amazon |

**Best Buy (if needed)**
| Item | Price | Link |
|---|---|---|
| USB-C Power Bank 20000mAh (powers Pi on bot) | ~$25 | [Best Buy](https://www.bestbuy.com/site/searchpage.jsp?st=power+bank) |
| MicroSD Card 32-64GB | ~$10 | [Best Buy](https://www.bestbuy.com/site/shop/raspberry-pi-micro-sd) |

**Already Owned**
- Raspberry Pi 5 (Alex — bringing to build sessions)
- Raspberry Pi 4 (Romeo, backup)
- Pico (Romeo, backup)
- MicroSD card (Romeo)
- SIM card (Romeo)
- Velcro strips (Romeo)

**Arrival Tracker (updated 3/12)**
| Item | Ordered | ETA | Status |
|---|---|-----|---|
| Pi Active Fan | 3/10 | 3/11 | **DELIVERED** — Romeo has it |
| LK-COKOINO 4WD Chassis (Alex) | 3/10 | 3/11 | **DELIVERED** — Alex has it |
| WWZMDiB L298N 2-Pack | 3/10 | 3/12 | **DELIVERED** — Romeo has it |
| DIYables HC-SR04 2-Pack | 3/10 | 3/12 | **DELIVERED** — Romeo has it |
| QTEATAK 18650 holders 8-Pack | 3/10 | 3/12 | **DELIVERED** — Romeo has it |
| Arducam Pan Tilt Platform | 3/10 | 3/12 | **DELIVERED** — Romeo has it |
| CanaKit 3.5A Pi PSU + PiSwitch | 3/11 | 3/12 | **DELIVERED** — Romeo has it |
| USB-C Right-Angle Adapter 2-Pack | 3/11 | 3/12 | **DELIVERED** — Romeo has it |
| Anker PowerCore 10K Power Bank | 3/11 | 3/13 | In transit — arriving tomorrow |
| ELEGOO HC-SR04 5-Pack | 3/10 | 3/13 | In transit — arriving tomorrow |
| 18650 batteries (4-pack) + charger | 3/11 | 3/15 | In transit — arriving Saturday |
| Arducam Camera Module 3 Wide (IMX708) | 3/10 | 3/15 | In transit — arriving Saturday |
| Arducam Ribbon Flex Extension Cable Set (7pc) | 3/17 | 3/18 | In transit — arriving tomorrow |
| 3ft Camera Ribbon Cable | 3/17 | 3/18 | In transit — for mast camera mounting |
| PVC Pipe 1" x 10ft + Tee fitting | — | **Pickup ready** | In HD cart ($8.09) — still needs pickup |

**Backup / Alternatives**
- [ ] ALAMSCN L293D Motor Driver + TT Motor Kit — [Amazon](https://www.amazon.com/ALAMSCN-Controller-Control-Expansion-Arduino/dp/B08Y24QBX3) — L293D shield (600mA/ch, lower than L298N's 2A). Backup if L298N doesn't work out.

**Still Needed**
- [x] ~~Motor driver board~~ — **DELIVERED 3/12** (WWZMDiB L298N 2-pack)
- [x] ~~Ultrasonic sensor~~ — **DIYables DELIVERED 3/12**, ELEGOO arriving 3/13
- [x] ~~Battery holders~~ — **DELIVERED 3/12** (QTEATAK 8-pack)
- [x] ~~Power bank for Pi~~ — Anker PowerCore 10K arriving 3/13
- [x] ~~MicroSD card~~ — **Romeo has one**

**Escort Bot Total: ~$103** (Romeo: ~$88 Amazon + ~$8 Home Depot. Alex covers chassis.)

### SO-101 Arm (~$295) — Ordered 2026-03-09
- [x] HiWonder LeRobot SO-ARM101 Kit — ~$270 (hiwonder.com) — **ETA ~3/18 (ships from China, 6 biz days)**
- [x] NexiGo N60 1080P Webcam — ~$25 (Amazon) — ETA 3/11
- [x] Raspberry Pi 5 or laptop — already owned

### Previously Ordered (3/9) — may overlap / backup
- [x] Freenove 4WD Smart Car Kit — ~$65 (Amazon) — ETA 3/11
- [x] Samsung 30Q 18650 batteries + charger — ~$18 (Amazon) — ETA 3/11
- [x] MakerFocus Pi Battery Pack 10000mAh — ~$30 (Amazon) — ETA 3/11

---

## Design Notes

### Escort Bot — Data Integration
The escort bot needs to connect to **Jira** and **NetBox** so it knows what devices are in what status. This enables the bot to be context-aware during vendor escorts — it can identify which rack/device the vendor is there to work on, what state the device is in (staged, provisioned, decommissioned, etc.), and cross-reference with open Jira tickets for that location. Romeo already has `JIRA_API_TOKEN` and `NETBOX_TOKEN` set in `~/.config/keys/global.env`, and the CW MCP server exposes `jira_search`, `netbox_find_device`, `netbox_rack_devices`, and `netbox_interfaces`.

---

## Key Decisions Made

| Decision | Chose | Over | Why |
|---|---|---|-----|
| Escort platform | Pi 5 + Freenove chassis | iRobot Create 3 | Already own Pi, $65 vs $300 |
| Detection model | YOLOv8n (Ultralytics) | MobileNet SSD, OpenCV DNN, HOG | Best accuracy on Pi 5, 0.78 confidence at DC floor, <100ms inference |
| Motor framework | gpiozero | ROS 2 | One file, zero setup overhead |
| Arm kit | HiWonder SO-ARM101 | Seeed Studio + 3D print | Faster, all parts included |
| Training policy | ACT (Action Chunking) | Diffusion, RL | LeRobot default, works with 50 demos |
| Demo task | Optic seating | Cable management, rack inspection | Most tractable, clear success/fail |

---

## What's Next

**See `COUNTDOWN.md` for the full day-by-day sprint plan (March 21-26).**

### Key Milestones
- **Friday 3/21:** Josh + Parth onsite — dashboard + bot integration testing
- **Saturday 3/22:** Josh 3D prints arm parts. Bot PID tuning.
- **Sunday 3/23:** Bot complete. Arm assembly begins.
- **Monday 3/24:** **ARM GO/NO-GO GATE.** Escort bot must be done. If arm not working → cut it.
- **Tuesday 3/25:** **FEATURE FREEZE at noon.** Record demo video. Submit.
- **Wednesday 3/26:** **DEMO DAY** (11am-2pm PT / 2pm-5pm ET)

### Current Status (updated 3/21)

**Escort Bot — Integration Phase (Josh + Parth onsite)**
- [x] All code built by Romeo (api_server.py, main.py, pan_tilt.py, dashboard)
- [x] Pi API server done — Flask, MJPEG, YOLOv8n, all endpoints
- [ ] Dashboard↔Pi connectivity test (set Pi IP in `escort.py` line 36)
- [ ] Xbox controller teleoperation
- [ ] YOLOv8n + PID person following on real hardware
- [ ] L298N 5V logic pin fix (if not already done)
- [ ] Ultrasonic sensor wired + tested
- [ ] PVC mast + camera elevation
- [ ] PID tuning for smooth following

**SO-101 Arm — Parts Just Arrived (3/21)**
- [ ] Josh received arm parts today
- [ ] 3D print arm components (3/22)
- [ ] Assemble arm (~2-3 hrs)
- [ ] Install LeRobot, calibrate servos (~1 hr)
- [ ] **GO/NO-GO: Monday 3/24 end of day**

**Demo / Presentation**
- [ ] Demo video (2:30 target) — script at `docs/DEMO-SCRIPT.md`
- [ ] Pitch deck — `pitch-deck.html`
- [ ] GitHub repo cleanup — README, screenshots
- [ ] Slides finalized
- [ ] Submit by end of Tuesday 3/25

### Completed
0. [x] Pi 5 desktop env + CLI tools + GUI apps — **Done 3/17**
0. [x] Tailscale VPN up on Pi — reachable at `100.85.225.68` — **Done 3/17**
0. [x] Python venv confirmed (torch, YOLOv8, picamera2, pillow) — **Done 3/17**
0. [x] Wiring guide completed through Step 6 — **Done 3/17**
0. [x] Motor blocker root cause found (L298N 5V logic pin) — **Found 3/17**
0. [x] 3ft camera ribbon cable ordered — **Ordered 3/17, ETA 3/18**
0. [x] Site audit: 25 pages deleted, hub rebuilt (5 phases/15 cards) — **Done 3/18**
0. [x] Parth confirmed for dashboard backend — **Agreed 3/18**
1. [x] Order Freenove kit + batteries + power bank — **Done 3/9**
2. [x] Order SO-ARM101 DIY kit + webcam — **Done 3/9**
3. [x] Create detailed parts list with Amazon links — **Done 3/9** (`PARTS-LIST.md`)
4. [x] Verify Freenove kit contents (motor driver, sensor, camera) — **Done 3/9**
5. [x] Create Pi 5 setup guide — **Done 3/9** (`escort-bot/PI-SETUP.md`)
6. [x] **Sign up for hackathon** — **Done 3/12** via `#more-faster-better-2026`
7. [x] Order Pi 5 Active Cooler (~$10) — **Ordered 3/10, ETA 3/11**
8. [x] Order Arducam Camera + Pan-Tilt — **Ordered 3/10, ETA 3/12-3/14**
9. [x] Write `elktron-app/api/arm.py` — LeRobot serial interface — **Done 3/10**
10. [x] Write `elktron-app/api/escort.py` — escort telemetry — **Done 3/10**
11. [x] Write `elktron-app/api/models.py` — Pydantic schemas — **Done 3/10**
12. [x] Build dashboard panels in `elktron-app/index.html` — **Already complete** (all 5 panels + JS + WebSocket)

### March 26 — Demo Day (11am–2pm PT / 2pm–5pm ET)

---

## File Map

```
hackathon/
├── CLAUDE.md                          # Hackathon root config
├── PROGRESS.md                        # THIS FILE — single source of truth
├── PARTS-LIST.md                      # Hardware BOM + Amazon links + costs
├── CHECKLIST-SO101.md                 # 10-phase arm build checklist
├── CHECKLIST-ESCORT-BOT.md            # 11-phase bot build checklist
├── VELOCITY.md                        # Engineering philosophy
├── WORKFLOW.md                        # Demo day timeline
├── escort-bot/
│   ├── main.py                        # Person-following robot brain (211 lines, complete)
│   ├── test_camera.py                 # Camera-only detection test (no motors)
│   ├── install.sh                     # Pi 5 software setup
│   ├── requirements.txt
│   ├── WIRING.md                      # GPIO + wiring diagrams
│   ├── PI-SETUP.md                    # Pi 5 OS flashing + first boot guide
│   └── showcase.html                  # Scope page
├── robotics-site/
│   ├── index.html                     # Elktron landing page
│   ├── CLAUDE.md                      # Robotics site config
│   └── so101/
│       ├── record.py                  # Record demos (scaffolded, ready)
│       ├── train.py                   # Train ACT policy (scaffolded, ready)
│       ├── deploy.py                  # Deploy autonomous (scaffolded, ready)
│       ├── install.sh                 # LeRobot setup
│       ├── requirements.txt
│       ├── HARDWARE.md                # BOM + assembly
│       └── showcase.html              # Scope page
└── elktron-app/
    ├── CLAUDE.md                      # Dashboard architecture spec
    ├── index.html                     # Dashboard UI (layout only, needs panels)
    └── api/
        ├── server.py                  # FastAPI + WebSocket (mock data, working)
        ├── arm.py                     # ✅ LeRobot Feetech motor bus interface
        ├── escort.py                  # ✅ Pi 5 telemetry + scan management
        └── models.py                  # ✅ Pydantic schemas (arm, escort, scan, training)
```

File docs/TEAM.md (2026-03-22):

# Elktron — Team & Roles

## Team Roster (6 active + 1 observer)

### Romeo Patino — Project Management (PM)
**Title:** Data Center Technician, Channel Manager
**Objective:** Own the system architecture, LeRobot integration, and demo narrative. Make sure all three components (arm, bot, dashboard) connect into one coherent story.

**Scope:**
- Overall project architecture and technical decisions
- LeRobot framework integration for SO-101 arm
- Escort bot software (main.py, test_camera.py)
- Elktron dashboard (elktron-app) — initial template + frontend
- Pi 5 setup and configuration
- PROGRESS.md — single source of truth
- Hardware ordering (Amazon, Home Depot)

**Hardware:** Pi 4, Pi 5, Pico, MacBook (training + demo)

---

### Joshua Tapia — Integration Lead + Robot Arm
**Title:** Data Center Technician
**Objective:** Own the end-to-end integration — dashboard, API pipeline, escort bot testing — plus SO-101 arm when hardware is ready. Good with API work.

**Scope:**
- **Dashboard + API integration** (active as of 3/21) — testing Pi→dashboard pipeline, Xbox controller teleoperation, YOLOv8n + PID following
- Computer vision pipeline for optic detection
- Inverse kinematics and motion planning
- End effector design — gripper for SFP/QSFP optics
- LeRobot ACT policy training and evaluation
- Record 50 optic seating demonstrations
- Arm calibration and servo tuning

**Hardware:** His laptop (dashboard), Pi 5 onsite, arm kit

---

### Alex Murillo — Escort Bot Hardware Lead
**Title:** Data Center Technician
**Objective:** Own the physical escort bot build — chassis assembly, wiring, motor tuning, and field testing on the DC floor.

**Scope:**
- LK-COKOINO chassis assembly and wiring
- PVC mast construction and camera mounting
- Motor + ultrasonic sensor integration
- Physical testing — drive, steer, obstacle avoidance
- DC floor field testing during escort bot tuning
- Power system — battery charging, cable routing

**Hardware:** Her Raspberry Pi, LK-COKOINO chassis

---

### Parth Patel — Pi Setup + Integration Support
**Title:** Data Center Technician
**Objective:** Support onsite integration work alongside Josh. Set up the Pi environment for the team.

**Actual contributions (as of 3/21):**
- Pi terminal/CLI setup — installed powerlevel10k, shell tools, developer QoL
- Onsite support — working with Josh on integration testing
- Has not written project code (api_server.py, dashboard, etc. were all built by Romeo)

**Scope going forward:**
- Support Josh on dashboard + API integration testing onsite
- Help with hardware testing and debugging
- Jira/NetBox data integration (stretch goal)

**Confirmed:** 2026-03-18 — agreed in `#the-elks-2026`

**Hardware:** Laptop + onsite Pi 5 access

---

### Talha Shakil — Media & Presentations Lead
**Title:** Data Center Technician
**Objective:** Own all final deliverables — demo video, pitch deck, team logo, and presentation materials. Make sure Elktron looks polished for judges.

**Scope:**
- Team logo design
- Demo video production (filming, editing, narration support)
- Pitch deck / slides (5-7 slides)
- Screen recordings of dashboard for video
- Final video export and upload
- B-roll footage (wiring, assembly, Pi boot, terminal output)

**Hardware:** Phone/camera for filming, laptop for editing

---

### Raphael Rodea — Build Crew + Logistics Lead
**Title:** Data Center Technician
**Objective:** Own all physical assembly, parts inventory, battery management, and demo day logistics. The reason the robots are built clean, charged, and present on Demo Day (March 26).

**Scope:**
- Chassis assembly — mount motors, attach wheels, screw standoffs (pairs with Alex)
- PVC mast build — cut pipe, attach T-connector, mount to chassis
- Wiring checker — verify every connection against WIRING.md (second pair of eyes)
- Cable management — route wires, velcro, zip tie, label everything
- Parts inventory — open packages, verify contents, label with tape, organize war room
- Battery manager — charge all batteries night before, swap during testing, track charge levels
- Demo day packing — owns the checklist, makes sure nothing gets left behind
- Floor testing safety — stands near bot, ready to grab it
- B-roll camera assist — film assembly and floor tests for Talha's video edit
- Plays "vendor" role during escort bot demo

**Hardware:** None needed — works with Alex's hardware

---

### Andrew Westberg — Observer
**Title:** Data Center Technician
**Objective:** Watch and learn. Not on the active roster.

**Scope:**
- Observing the build process
- Learning robotics, Pi setup, and hackathon workflow
- Available to help if needed, but no assigned tasks

---

## Communication
- **Slack:** `#the-elks-2026` (team) · `#more-faster-better-2026` (hackathon)
- **Daily sync:** Share updates in team Slack each morning
- **Decisions:** Update PROGRESS.md — single source of truth
- **Rule:** Everyone owns their lane. Nobody waits for permission.

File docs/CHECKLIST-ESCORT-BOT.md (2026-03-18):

# Escort Bot — Full Build Checklist

> Elktron Hackathon | CoreWeave March 2026
> Platform: Raspberry Pi 5 + 4WD Chassis | CV: YOLOv8n (switched from OpenCV DNN MobileNet SSD v2)

---

## Phase 1: Procurement & Inventory

### Parts Sourcing
- [x] ~~Order 4WD chassis~~ — **LK-COKOINO 4WD kit — Alex has it**
- [x] ~~Order HC-SR04 ultrasonic sensor~~ — **DIYables 2-pack DELIVERED 3/12 + ELEGOO 5-pack arriving 3/13**
- [x] ~~Order Pi Camera Module 3 (CSI)~~ — **Arducam IMX708 Wide arriving Sat 3/15**
- [x] ~~Order motor driver~~ — **L298N 2-pack DELIVERED 3/12**
- [x] ~~Order battery holders~~ — **QTEATAK 8-pack DELIVERED 3/12**
- [x] ~~Order 18650 batteries~~ — **QOJH 4-pack arriving Sat 3/15**
- [x] ~~Order USB-C power bank~~ — **Anker PowerCore 10K arriving 3/13**
- [x] ~~Order pan/tilt platform~~ — **Arducam Pan Tilt DELIVERED 3/12**
- [x] ~~Order CSI ribbon extension cables~~ — **Arducam 7pc Flex Cable Set ORDERED 3/17, arriving 3/18** ($10.71)
- [x] ~~Order CanaKit Pi PSU~~ — **DELIVERED 3/12 (bench testing only)**
- [x] ~~Order USB-C right-angle adapter~~ — **Silkland 2-pack DELIVERED 3/12**
- [ ] Order jumper wires: 20x male-to-female, 10x male-to-male (ELEGOO 5-pack comes with 20 dupont cables — may suffice)
- [ ] Order breadboard (half-size) — for prototyping sensor connections
- [ ] Order 1kΩ and 2kΩ resistors (2 each) — voltage divider for HC-SR04 ECHO pin
- [ ] Optional: LED strip or indicator LEDs — visual status feedback
- [ ] Optional: small speaker/buzzer — audio alerts

### Inventory Check (before assembly day)
- [x] Raspberry Pi 5 — Alex has it, confirmed working
- [x] MicroSD card (32GB+) — Romeo has one, needs flashing with Bookworm Lite 64-bit
- [x] USB-C power supply for Pi 5 — CanaKit 3.5A DELIVERED 3/12 (bench testing)
- [ ] USB-C power bank for mobile operation — Anker arriving 3/13
- [x] 4WD chassis kit — Alex has it (LK-COKOINO)
- [x] L298N motor driver board — DELIVERED 3/12 (2-pack, have spare)
- [x] HC-SR04 ultrasonic sensor — DIYables 2-pack DELIVERED 3/12
- [x] ~~Camera (Arducam IMX708 Wide)~~ — **DELIVERED + WORKING 3/16**
- [ ] 18650 batteries — arriving Sat 3/15
- [ ] Jumper wires (male-to-female, male-to-male)
- [ ] Breadboard
- [ ] Resistors (1kΩ, 2kΩ) for voltage divider
- [ ] Small Phillips and flathead screwdrivers
- [ ] Wire strippers (if using raw wire)
- [ ] Electrical tape or heat shrink tubing
- [ ] Velcro strips for cable management
- [ ] Double-sided tape or mounting brackets for Pi + camera

---

## Phase 2: Raspberry Pi Setup

### OS Installation
- [ ] Download Raspberry Pi OS (64-bit, Bookworm) — use Raspberry Pi Imager
- [ ] Flash to MicroSD card
- [ ] Pre-configure WiFi + SSH in Imager settings (for headless access)
- [ ] Set hostname: `elktron-escort`
- [ ] Set username/password
- [ ] Insert MicroSD into Pi 5, boot up
- [ ] Verify boot — SSH in: `ssh <user>@elktron-escort.local`
- [ ] Run system update: `sudo apt update && sudo apt upgrade -y`
- [ ] Verify Python 3.11+: `python3 --version`

### Claude Code (AI Dev on Pi)
- [x] Install Claude Code CLI on Pi 5 — **DONE 2026-03-15**
- [ ] Verify: `ssh pi@escort-bot.local` → `cd ~/escort-bot` → `claude` launches successfully
- [ ] Test: ask Claude to read a sensor value or run `test_camera.py` from within the CLI

### Enable Interfaces
- [ ] Enable Camera (CSI): `sudo raspi-config` → Interface Options → Camera → Enable
- [ ] Enable I2C (if using I2C sensors): `sudo raspi-config` → Interface Options → I2C → Enable
- [ ] Enable SPI (if needed): same path
- [ ] Reboot after interface changes: `sudo reboot`

### Camera Test
- [x] ~~Pi Camera Module: `libcamera-hello --timeout 5000`~~ — **WORKING, libcamera v0.7.0**
- [ ] USB webcam: `ls /dev/video*` — should show device
- [ ] Python test: `python3 -c "import cv2; cap=cv2.VideoCapture(0); ret,f=cap.read(); print(ret, f.shape); cap.release()"`
- [x] ~~Verify resolution: at least 640x480~~ — **CONFIRMED**
- [x] ~~Verify FPS: at least 15 FPS (20+ preferred)~~ — **CONFIRMED**
- [x] ~~If using picamera2: `python3 -c "from picamera2 import Picamera2; cam=Picamera2(); cam.start(); print('OK'); cam.stop()"`~~ — **WORKING**

### GPIO Test
- [ ] Install gpiozero: `pip3 install gpiozero lgpio`
- [ ] Test basic GPIO: `python3 -c "from gpiozero import LED; import time; led=LED(17); led.on(); time.sleep(1); led.off()"` (connect an LED to GPIO17 to verify)
- [ ] If GPIO permission error: add user to gpio group: `sudo usermod -aG gpio $USER`
- [ ] Verify lgpio backend works (Pi 5 uses lgpio, not RPi.GPIO)

---

## Phase 3: Chassis Assembly

### Base Chassis
- [ ] Identify top and bottom chassis plates
- [x] Mount 4 DC motors to bottom plate using brackets + screws
- [x] Verify motor shafts face outward (toward wheels)
- [x] Attach 4 wheels to motor shafts — press fit, should be snug
- [x] Spin each wheel by hand — motors should spin freely, no grinding
- [ ] Label motors: FL (front-left), FR (front-right), RL (rear-left), RR (rear-right)
- [ ] Mount standoffs between bottom and top plates (4–6 standoffs typical)
- [ ] Attach top plate — leave enough clearance for wires between plates

### Motor Wiring
- [ ] Solder or connect motor leads (2 wires per motor, 8 total)
- [ ] Route motor wires to center of chassis where L298N will mount
- [x] Left motors (FL + RL): wire in parallel — red to red, black to black
- [x] Right motors (FR + RR): wire in parallel — red to red, black to black
- [x] Result: 2 wire pairs — LEFT pair and RIGHT pair
- [ ] Verify polarity: when positive voltage applied, wheels spin FORWARD (test with battery briefly)
- [ ] If wheels spin backward: swap the two wires for that motor pair

### L298N Motor Driver Mounting
- [ ] Mount L298N board on top plate using standoffs or double-sided tape
- [ ] Connect LEFT motor pair to L298N OUT1 + OUT2 terminals
- [ ] Connect RIGHT motor pair to L298N OUT3 + OUT4 terminals
- [ ] Tighten screw terminals firmly — loose connections = intermittent motor failure
- [x] Connect battery pack positive to L298N +12V (VCC) terminal
- [x] Connect battery pack negative to L298N GND terminal
- [ ] Verify 5V jumper on L298N:
  - If jumper IN: L298N regulates 5V from motor battery (can power Pi — risky, noisy)
  - If jumper OUT: L298N only gets motor power, Pi needs separate power (RECOMMENDED)
- [ ] Remove 5V jumper — power Pi separately via USB-C power bank

### L298N to Pi GPIO Connections
```
L298N Pin    →    Pi GPIO (BCM)    Purpose
─────────────────────────────────────────────
IN1          →    GPIO 17          Left motor forward
IN2          →    GPIO 24          Left motor backward
IN3          →    GPIO 22          Right motor forward
IN4          →    GPIO 23          Right motor backward
ENA          →    GPIO 12 (PWM)    Left motor speed (optional)
ENB          →    GPIO 13 (PWM)    Right motor speed (optional)
GND          →    Pi GND           Common ground (CRITICAL)
```

- [ ] Connect IN1 → GPIO 17 (jumper wire)
- [ ] Connect IN2 → GPIO 24
- [ ] Connect IN3 → GPIO 22
- [ ] Connect IN4 → GPIO 23
- [ ] Connect L298N GND → Pi GND pin (pin 6, 9, 14, 20, 25, 30, 34, or 39)
- [ ] **CRITICAL:** Common ground between L298N and Pi — without this, GPIO signals are unreliable
- [ ] Optional: Connect ENA → GPIO 12, ENB → GPIO 13 for PWM speed control
- [ ] If ENA/ENB not used: leave jumpers on ENA/ENB pins (full speed always)

### Motor Test (after wiring)
- [ ] Power on Pi + motor battery
- [ ] Run quick test script:
```python
from gpiozero import Robot
robot = Robot(left=(17, 24), right=(22, 23))
robot.forward(speed=0.3)   # slow forward, 2 seconds
import time; time.sleep(2)
robot.stop()
```
- [ ] Verify: all 4 wheels spin forward
- [ ] Test: `robot.backward(0.3)` — all wheels spin backward
- [ ] Test: `robot.left(0.3)` — left wheels stop/reverse, right wheels forward (turns left)
- [ ] Test: `robot.right(0.3)` — right wheels stop/reverse, left wheels forward (turns right)
- [ ] If turning is reversed: swap LEFT and RIGHT motor pair connections on L298N
- [ ] If one side spins wrong direction: swap the two wires for that motor pair

---

## Phase 4: Sensor Integration

### Ultrasonic Sensor (HC-SR04)
```
HC-SR04 Pin    →    Connection              Purpose
──────────────────────────────────────────────────
VCC            →    Pi 5V (pin 2 or 4)      Power
GND            →    Pi GND                   Ground
TRIG           →    GPIO 25                  Trigger pulse (output)
ECHO           →    Voltage divider → GPIO 24   Echo return (input)
```

**IMPORTANT:** HC-SR04 ECHO pin outputs 5V. Pi 5 GPIO is 3.3V tolerant only. You MUST use a voltage divider.

#### Voltage Divider Wiring
- [ ] Connect ECHO pin → 1kΩ resistor → junction point
- [ ] Connect junction point → 2kΩ resistor → GND
- [ ] Connect junction point → GPIO 24
- [ ] This divides 5V to ~3.3V (safe for Pi GPIO)
- [ ] Double-check resistor values: 1kΩ (brown-black-red) and 2kΩ (red-black-red)

#### HC-SR04 Assembly
- [ ] Mount HC-SR04 on front of chassis — facing forward, slightly angled down
- [ ] Sensor should be ~5–10cm above ground level
- [ ] Secure with hot glue, mounting bracket, or velcro
- [ ] Connect VCC → Pi 5V
- [ ] Connect GND → Pi GND
- [ ] Connect TRIG → GPIO 25
- [ ] Connect ECHO → voltage divider → GPIO 24
- [ ] Verify wiring 3 times before powering on (wrong connection can damage Pi)

#### Ultrasonic Test
- [ ] Run test:
```python
from gpiozero import DistanceSensor
sonar = DistanceSensor(echo=26, trigger=25, max_distance=2)
while True:
    print(f"Distance: {sonar.distance * 100:.1f} cm")
    import time; time.sleep(0.5)
```
- [ ] Hold hand at 30cm → reading should be ~30cm (±5cm)
- [ ] Hold hand at 100cm → reading should be ~100cm
- [ ] Remove hand → reading should be >150cm or max
- [ ] Verify readings are stable (not jumping wildly)
- [ ] If readings are always 0 or max: check wiring, especially voltage divider

### Camera Mounting
- [ ] Mount camera on TOP of chassis, facing forward
- [ ] Angle: slightly downward (~10–15 degrees) to see both floor and standing person
- [ ] Secure camera with bracket, velcro, or double-sided tape
- [ ] Verify camera has clear FOV — no chassis parts blocking view
- [ ] Camera cable routed cleanly — not near motor wires (EMI interference)
- [x] ~~Test camera still works after mounting: `libcamera-hello` or OpenCV test~~ — **CONFIRMED via camtest.py**

---

## Phase 5: Software Setup

### System Dependencies
- [ ] Run: `sudo apt install -y python3-pip python3-venv libatlas-base-dev libjpeg-dev libopenjp2-7-dev`
- [ ] Run: `sudo apt install -y python3-opencv` (system OpenCV, faster than pip)
- [ ] Run: `sudo apt install -y libcamera-apps` (if using Pi Camera Module)

### Python Environment
- [ ] Create venv: `python3 -m venv ~/escort-env`
- [ ] Activate: `source ~/escort-env/bin/activate`
- [ ] Install deps from `requirements.txt`: `pip install -r ~/hackathon/escort-bot/requirements.txt`
- [ ] Expected packages: `numpy`, `opencv-python` (or `python3-opencv`), `gpiozero`, `lgpio`, `picamera2`
- [ ] If `opencv-python` fails on Pi 5: use system package instead: `sudo apt install python3-opencv`

### Model Setup
- [ ] Download MobileNet SSD v2 (COCO) for OpenCV DNN:
```bash
mkdir -p ~/models
wget -O ~/models/frozen_inference_graph.pb http://download.tensorflow.org/models/object_detection/ssd_mobilenet_v2_coco_2018_03_29.tar.gz
# Extract the .pb from the tarball, or use escort-bot/install.sh
wget -O ~/models/ssd_mobilenet_v2_coco.pbtxt https://raw.githubusercontent.com/opencv/opencv_extra/master/testdata/dnn/ssd_mobilenet_v2_coco_2018_03_29.pbtxt
```
- [ ] Run `escort-bot/install.sh` — it downloads model + COCO labels
- [ ] Verify model files exist: `ls -la ~/models/frozen_inference_graph.pb ~/models/ssd_mobilenet_v2_coco.pbtxt`
- [ ] Download COCO labels file: `~/models/coco_labels.txt`
- [ ] Verify "person" is class 1 in labels file (COCO class IDs)

### Model Test (no motors)
- [ ] Run detection test:
```python
import cv2
import numpy as np

net = cv2.dnn.readNetFromTensorflow(
    "models/frozen_inference_graph.pb",
    "models/ssd_mobilenet_v2_coco.pbtxt"
)

cap = cv2.VideoCapture(0)
ret, frame = cap.read()
blob = cv2.dnn.blobFromImage(frame, size=(300, 300), swapRB=True)
net.setInput(blob)
detections = net.forward()
# ... check detections for person class (class_id == 1) with confidence > 0.5
print("Person detected!" if person_found else "No person")
cap.release()
```
- [x] ~~Stand in front of camera (~1-2m away)~~ — **DONE**
- [x] ~~Verify: "person" class detected with confidence >0.5~~ — **YOLOv8n, 0.78 confidence at DC floor conditions**
- [x] ~~Check inference time: should be <100ms per frame on Pi 5~~ — **CONFIRMED <100ms**
- [ ] If too slow: ensure using quantized (uint8) model, not float32

---

## Phase 6: Person-Following Algorithm

### Core Logic (from `escort-bot/main.py`)
```
Loop:
  1. Capture frame from camera
  2. Run OpenCV DNN inference → detect persons
  3. Find largest person bounding box (closest person)
  4. Calculate error_x = (bbox_center_x - frame_center_x) / frame_width
  5. Calculate area_ratio = bbox_area / frame_area
  6. Steering: left_speed = BASE_SPEED - error_x * KP
              right_speed = BASE_SPEED + error_x * KP
  7. Distance: if area_ratio > TARGET → too close → slow down/stop
              if area_ratio < TARGET → too far → speed up
  8. Obstacle: if sonar < STOP_DISTANCE → emergency stop
  9. Lost: if no person for LOST_TIMEOUT → stop and wait
```

### Parameter Tuning Reference
| Parameter | Default | Range | What it does |
|---|---|---|---|
| `CONFIDENCE_THRESHOLD` | 0.5 | 0.3–0.7 | Min detection confidence (lower = more false positives) |
| `BASE_SPEED` | 0.5 | 0.2–0.8 | Forward speed (higher = faster but harder to steer) |
| `STOP_DISTANCE` | 0.30m | 0.15–0.50m | Ultrasonic emergency stop distance |
| `TARGET_AREA_RATIO` | 0.15 | 0.05–0.30 | How close to follow (bigger = closer) |
| `AREA_TOLERANCE` | 0.05 | 0.02–0.10 | Dead zone around target distance |
| `LOST_TIMEOUT` | 1.5s | 0.5–3.0s | Time without person before stopping |
| `KP` | 1.0 | 0.5–2.0 | Steering gain (higher = sharper turns) |
| `FRAME_WIDTH` | 320 | 160–640 | Detection resolution (lower = faster, less accurate) |

### Implementation Checklist
- [ ] Copy `escort-bot/main.py` to Pi: `scp main.py pi@elktron-escort.local:~/`
- [ ] Edit config section at top of `main.py` — set GPIO pins to match wiring
- [ ] Edit camera index (0 for USB, or picamera2 path for CSI)
- [ ] Edit model path to match where model was downloaded

### Bench Test (wheels off ground)
- [ ] Prop chassis up so wheels spin freely (put on a box)
- [ ] Run `main.py`
- [ ] Stand in front of camera → wheels should spin forward
- [ ] Move LEFT → right wheels should speed up (bot turns left to track you)
- [ ] Move RIGHT → left wheels should speed up (bot turns right)
- [ ] Walk away → wheels speed up (bot tries to close distance)
- [ ] Walk closer → wheels slow down or stop
- [ ] Disappear from frame → wheels stop after LOST_TIMEOUT
- [ ] Hold hand in front of ultrasonic (<30cm) → wheels stop immediately (emergency stop)
- [ ] If steering is reversed: swap left/right GPIO pins in config
- [ ] If forward/backward reversed: swap forward/backward GPIO pins

---

## Phase 7: Floor Testing

### Safety Precautions
- [ ] Test in open area first — no expensive equipment nearby
- [ ] Have someone ready to pick up the bot if it goes rogue
- [ ] Start with LOW speed: `BASE_SPEED = 0.2`
- [ ] Keep laptop nearby with SSH session open to kill the script: `Ctrl+C`
- [ ] Battery fully charged before floor test
- [ ] Test on smooth floor (not carpet — 4WD works but drains battery fast on carpet)

### Basic Movement Test
- [ ] Place bot on floor, run `main.py`
- [ ] Stand 2m in front → bot should move toward you slowly
- [ ] Walk forward slowly → bot follows
- [ ] Stop → bot stops (within 0.5–1m)
- [ ] Turn left → bot turns left
- [ ] Turn right → bot turns right
- [ ] Walk behind a pillar → bot stops after LOST_TIMEOUT

### Tuning Session (expect 30–60 minutes)
- [ ] If bot oscillates left-right: REDUCE `KP` (e.g., 1.0 → 0.6)
- [ ] If bot doesn't turn enough: INCREASE `KP` (e.g., 1.0 → 1.5)
- [ ] If bot follows too close: DECREASE `TARGET_AREA_RATIO` (e.g., 0.15 → 0.10)
- [ ] If bot stays too far: INCREASE `TARGET_AREA_RATIO` (e.g., 0.15 → 0.20)
- [ ] If bot loses person too easily: DECREASE `CONFIDENCE_THRESHOLD` (e.g., 0.5 → 0.35)
- [ ] If bot follows wrong things (not people): INCREASE `CONFIDENCE_THRESHOLD`
- [ ] If bot is too slow: INCREASE `BASE_SPEED` gradually (0.5 → 0.6 → 0.7)
- [ ] If bot is jerky: add smoothing to speed commands (exponential moving average)
- [ ] Tune until bot can follow a walking person for 30+ seconds continuously
- [ ] Note final parameter values — these are your "golden config"

### Edge Cases to Test
- [ ] Two people in frame → bot should follow the closest (largest bbox)
- [ ] Person walking fast → bot should try to keep up (may lose them — that's OK)
- [ ] Person standing still → bot should stop at target distance
- [ ] Obstacle between bot and person → ultrasonic stops bot, doesn't ram obstacle
- [ ] Lighting change (bright hallway → dim aisle) → detection still works?
- [ ] Person wearing dark clothing → detection still works?
- [ ] Person carrying a box (partially occluded) → detection still works?

### Battery Life Test
- [ ] Fully charge batteries
- [ ] Run continuous following test
- [ ] Time how long until motors weaken or Pi browns out
- [ ] Target: at least 30 minutes of operation for demo day
- [ ] If battery life too short: get higher capacity pack or carry spare

---

## Phase 8: DC-Specific Features

### Vendor Escort Scenario
- [ ] Define escort route: entrance → aisle → specific rack → back to entrance
- [ ] Bot follows vendor (person-following mode)
- [ ] At destination rack: bot stops and enters "monitoring mode"
- [ ] Monitoring mode: camera captures video of vendor working on rack
- [ ] Optional: log timestamp + rack ID + vendor name to scan report JSON

### Rack Contact Detection (stretch goal)
- [ ] Define rack zones in camera frame (if camera is static at rack)
- [ ] Detect if person's hands enter unauthorized rack unit zone
- [ ] Trigger alert (LED, buzzer, or dashboard notification)
- [ ] Log event to scan report JSON
- [ ] This is a STRETCH GOAL — skip if time is tight

### Status Indicators
- [ ] LED: Green = following, Yellow = searching, Red = obstacle stop
- [ ] Optional: buzzer beep on person lost
- [ ] Optional: buzzer pattern on escort complete
- [ ] If no LEDs: use print statements + dashboard for status

### Autonomous Navigation (stretch goal)
- [ ] Pre-program aisle waypoints (x, y coordinates or timed sequences)
- [ ] Bot navigates to rack autonomously using dead reckoning or waypoints
- [ ] This is a MAJOR stretch — only attempt if person-following works perfectly
- [ ] Simpler alternative: bot just follows vendor (no autonomous nav needed)

---

## Phase 9: Dashboard Integration

### WebSocket Connection
- [ ] `main.py` sends telemetry to Elktron dashboard via WebSocket
- [ ] Telemetry payload:
```json
{
  "type": "escort_status",
  "state": "following",        // following | searching | stopped | obstacle
  "person_detected": true,
  "confidence": 0.87,
  "bbox": [120, 80, 280, 400],
  "distance_m": 1.5,
  "sonar_cm": 95,
  "speed_left": 0.45,
  "speed_right": 0.52,
  "battery_v": 7.2,
  "uptime_s": 342
}
```
- [ ] Dashboard receives and displays: state, person detection, distance, sonar reading
- [ ] Dashboard shows live camera feed (WebSocket binary frames or MJPEG stream)
- [ ] If no live connection: use mock data for dashboard demo (JSON replay)

### Camera Streaming
- [ ] Option A: MJPEG over HTTP — `http://<pi-ip>:8080/stream`
  - Use `picamera2` with MJPEG server or `cv2` with Flask
  - Lower latency, simpler
- [ ] Option B: WebSocket binary frames
  - Encode each frame as JPEG, send via WebSocket
  - Integrates with existing dashboard WebSocket
- [ ] Test stream from another machine: open browser to MJPEG URL or check dashboard
- [ ] Verify latency: <500ms acceptable, <200ms ideal

---

## Phase 10: Demo Preparation

### Demo Setup
- [ ] Fully charged batteries (both motor pack and Pi power bank)
- [ ] Spare batteries on standby
- [ ] Clear demo area: 3m x 5m minimum, no tripping hazards
- [ ] Good lighting in demo area
- [ ] WiFi connection stable (for dashboard communication)
- [ ] Laptop showing Elktron dashboard nearby
- [ ] "Vendor" (team member) knows the walk route

### Demo Script (60 seconds)
- [ ] 0:00–0:10 — Show bot on floor, dashboard showing "IDLE"
- [ ] 0:10–0:15 — Narrate: "Escort bot autonomously follows vendors on the DC floor"
- [ ] 0:15–0:20 — "Vendor" starts walking, bot begins following
- [ ] 0:20–0:40 — Bot follows vendor through demo aisle (20 seconds of following)
- [ ] 0:40–0:50 — Vendor stops at "rack," bot stops at target distance
- [ ] 0:50–0:55 — Dashboard shows: escort status, camera feed, vendor position
- [ ] 0:55–1:00 — "Person detection using OpenCV DNN on Raspberry Pi 5, <100ms inference"

### Video Recording
- [ ] Record from a third-person angle — shows both vendor and bot moving
- [ ] Also record dashboard screen (screen capture or second camera)
- [ ] Record 5+ takes — pick the smoothest one
- [ ] Audio: clear narration explaining what's happening
- [ ] Video: 1080p, well-lit, shows bot's movement clearly
- [ ] Include a moment where bot successfully turns a corner following vendor
- [ ] Total escort bot segment: 60 seconds max for the 3-minute final video

### Failsafe Plan
- [ ] If bot won't follow: switch to manual RC control + narrate the vision
- [ ] If Pi camera fails: swap to USB webcam (bring both)
- [ ] If WiFi fails: run dashboard locally on Pi, screen-share via HDMI
- [ ] If motors die: show detection working on screen (person tracking without movement)
- [ ] If battery dies mid-demo: have spare fully charged pack ready to swap

---

## Phase 11: Pre-Hackathon Integration Test

### Full System Test (do this at least 2 days before demo day)
- [ ] Both robots running simultaneously
- [ ] Dashboard receiving telemetry from both (arm + escort bot)
- [ ] Camera feeds streaming from both
- [ ] Run full demo script end-to-end
- [ ] Time the full demo — must be under 3 minutes total
- [ ] Record a practice video — review for issues
- [ ] Fix any issues found
- [ ] Run full demo script again — confirm fixes

### Network Test
- [ ] Pi 5 and laptop on same WiFi network
- [ ] WebSocket connections stable for 5+ minutes
- [ ] No firewall blocking local traffic
- [ ] If venue WiFi is unreliable: bring a portable WiFi router or use Pi as hotspot

### Stress Test
- [ ] Run escort bot for 15+ minutes continuous
- [ ] Check: motors still responsive? Pi overheating? Battery holding?
- [ ] If Pi overheats: add heatsink or small fan
- [ ] If motors weaken: check battery voltage, swap if <6.5V (for 7.4V pack)
- [ ] Run through demo script 3x consecutively without stopping

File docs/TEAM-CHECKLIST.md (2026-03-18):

# Elktron — Master Team Checklist

> **Submissions closed:** March 12, 2026 | **Hackathon:** March 23–25 | **Demo Day:** March 26 (11am–2pm PT / 2pm–5pm ET)
> **Deliverable:** 2–3 min pre-recorded demo + optional slides + GitHub repo
> **Track:** Build with Velocity
> **Last updated:** 2026-03-11

---

## Team Roster

| Name | Role | Owns |
|---|---|---|
| **Romeo Patino** | Lead — architecture, software, demo story | System design, escort bot software, dashboard frontend, Pi setup |
| **Joshua Tapia** | Robot arm — CV, positioning, training | SO-101 assembly, calibration, ACT policy, optic seating demo |
| **Alex Murillo** | Escort bot hardware lead | Chassis build, wiring, motor/sensor integration, floor testing |
| **Parth Patel** | Backend lead | FastAPI server, Jira/NetBox data integration, WebSocket pipeline |
| **Talha Shakil** | Media & presentations | Demo video, pitch deck, logo, filming, editing |
| **Raphael Rodea** | Build crew + logistics | Assembly, parts inventory, batteries, wiring checks, packing, demo day "vendor" |
| **Andrew Westberg** | Observer | Watching and learning — not on active roster |

---

## How to Use This Checklist

- **Claim a task:** Put your name in the `Owner` column
- **Mark done:** Change `[ ]` to `[x]`
- **Blocked?** Add `BLOCKED:` + reason next to the task
- **Questions?** Drop them in `#more-faster-better-2026` or DM Romeo
- **Rule:** If a task takes >2 hours and you're stuck, ask for help. Don't spin.

---

## PHASE 0: ADMIN & SIGN-UP (by March 12 — TOMORROW)

| # | Task | Owner | Status | Notes |
|---|---|---|---|---|
| 0.1 | Sign up team in `#more-faster-better-2026` | Romeo | [ ] | **DEADLINE MARCH 12** — list all 7 names |
| 0.2 | Confirm all team members have Slack access to hackathon channel | Romeo | [ ] | DM each person |
| 0.3 | Create shared GitHub repo for Elktron | Romeo | [ ] | Private repo, add all members as collaborators |
| 0.4 | Share this checklist with the team (link or copy) | Romeo | [ ] | Pin in hackathon channel |
| 0.5 | Confirm everyone has read VELOCITY.md | All | [ ] | Sets the pace expectation |
| 0.6 | Each person confirms their availability March 20-23 | All | [ ] | Note any conflicts |
| 0.7 | Identify who has a car / can pick up Home Depot items | All | [ ] | PVC pipe + T-connector still need pickup |
| 0.8 | Pick up PVC pipe 1" x 4ft + T-connector from Home Depot | Romeo or volunteer | [ ] | Already in HD cart ($8.09) |

---

## PHASE 1: HARDWARE INTAKE & INVENTORY (March 11–13)

### 1A: Receive & Verify Shipments

Every package that arrives — open it, verify contents, mark done.

| # | Task | Owner | ETA | Status | Notes |
|---|---|---|-----|---|---|
| 1A.1 | Receive Pi 5 Active Cooler | Romeo | 3/11 | [ ] | Check box, verify fan + heatsink + thermal pad included |
| 1A.2 | Receive LK-COKOINO 4WD Chassis Kit | Alex | 3/11 | [ ] | Verify: 4 motors, 4 wheels, chassis plates, screws, standoffs |
| 1A.3 | Receive Samsung 30Q 18650 batteries + charger | Romeo | 3/11 | [ ] | Start charging batteries IMMEDIATELY — takes 4-6 hours |
| 1A.4 | Receive MakerFocus Pi battery pack 10000mAh | Romeo | 3/11 | [ ] | Verify USB-C output, charge to 100% |
| 1A.5 | Receive WWZMDiB L298N Motor Driver 2-pack | Romeo | 3/12 | [ ] | Test one board — LEDs light up when powered |
| 1A.6 | Receive ELEGOO HC-SR04 Ultrasonic 5-pack | Romeo | 3/12 | [ ] | Keep 2 for build, rest are spares |
| 1A.7 | Receive DIYables HC-SR04 2-pack | Romeo | 3/12 | [ ] | Backup ultrasonic sensors |
| 1A.8 | Receive QTEATAK 18650 Battery Holders 8-pack | Romeo | 3/12 | [ ] | Need 1 for chassis, rest are spares |
| 1A.9 | Receive Arducam Pan-Tilt Platform (2 servos + controller) | Romeo | 3/12 | [ ] | Verify 2 servos + mounting hardware included |
| 1A.10 | Receive Arducam 120° Wide Camera (IMX708) | Romeo | 3/14 | [ ] | **Camera is the last escort bot part** — verify CSI cable included |
| 1A.11 | Receive Freenove 4WD Smart Car Kit (backup/parts) | Romeo | 3/11 | [ ] | Originally ordered — may use parts or keep as backup |
| 1A.12 | Receive NexiGo N60 1080P Webcam | Romeo | 3/11 | [ ] | For SO-101 arm overhead camera |
| 1A.13 | SO-101 arm kit (HiWonder) — LONG POLE | Romeo | ~3/18 | [ ] | Ships from China. If delayed, arm demo uses pre-recorded video |

### 1B: Inventory & Organize

| # | Task | Owner | Status | Notes |
|---|---|---|---|---|
| 1B.1 | Gather owned hardware: Pi 4, Pi 5, Pico, SIM card, velcro | Romeo | [ ] | From home — put in one box |
| 1B.2 | Find or buy MicroSD card 32-64GB for Pi 5 | Romeo | [ ] | Check drawer first. If not: Samsung EVO Select 64GB ~$8 |
| 1B.3 | Find USB-C data cables (not charge-only) x3 | All | [ ] | Test each cable — plug into laptop, run `ls /dev/tty*` |
| 1B.4 | Find small Phillips screwdriver set | All | [ ] | For chassis + arm assembly |
| 1B.5 | Find wire strippers or scissors for jumper wire prep | All | [ ] | For voltage divider + custom wiring |
| 1B.6 | Collect jumper wires: 20x M-F, 10x M-M | Romeo | [ ] | If not enough: buy assorted pack ~$6 |
| 1B.7 | Get breadboard (half-size) | Romeo | [ ] | For prototyping ultrasonic voltage divider |
| 1B.8 | Get resistors: 1kΩ (x2) and 2kΩ (x2) | Romeo | [ ] | For HC-SR04 ECHO pin voltage divider (5V → 3.3V) |
| 1B.9 | Label all parts with masking tape — write what each thing is | Anyone | [ ] | Prevents confusion during assembly |
| 1B.10 | Create a "war room" table/area for assembly | Romeo | [ ] | Dedicated space, good lighting, power strips |

---

## PHASE 2: RASPBERRY PI SETUP (March 11–12)

This can start immediately — only needs Pi 5 + MicroSD + power.

| # | Task | Owner | Status | Notes |
|---|---|---|---|---|
| 2.1 | Download Raspberry Pi Imager on Mac | Romeo | [ ] | https://downloads.raspberrypi.com/imager/imager_latest.dmg |
| 2.2 | Flash MicroSD: Raspberry Pi OS Lite (64-bit, Bookworm) | Romeo | [ ] | In Imager: set hostname `elktron-escort`, enable SSH, set WiFi |
| 2.3 | Set username: `elktron` / password: [choose one, share with team] | Romeo | [ ] | Everyone needs SSH access |
| 2.4 | Insert MicroSD into Pi 5, connect USB-C power, boot | Romeo | [ ] | Green LED blinks = booting. Wait 60 seconds. |
| 2.5 | SSH into Pi: `ssh elktron@elktron-escort.local` | Romeo | [ ] | If .local doesn't resolve: find IP from router or `nmap -sn 192.168.x.0/24` |
| 2.6 | Run system update: `sudo apt update && sudo apt upgrade -y` | Romeo | [ ] | Takes 5–15 min depending on network |
| 2.7 | Verify Python version: `python3 --version` → should be 3.11+ | Romeo | [ ] | Bookworm ships 3.11 |
| 2.8 | Install Pi 5 Active Cooler (physical install) | Romeo | [ ] | 4 screws, thermal pad, plug fan into Pi 5 header |
| 2.9 | Verify cooler works: `cat /sys/class/thermal/thermal_zone0/temp` → should drop under load | Romeo | [ ] | Run `stress --cpu 4 --timeout 30s` and check temp stays <70°C |
| 2.10 | Enable Camera interface: `sudo raspi-config` → Interface → Camera | Romeo | [ ] | Reboot after |
| 2.11 | Enable I2C: `sudo raspi-config` → Interface → I2C | Romeo | [ ] | For pan-tilt servo controller |
| 2.12 | Install system deps: `sudo apt install -y python3-pip python3-venv libatlas-base-dev libjpeg-dev python3-opencv libcamera-apps` | Romeo | [ ] | One command, ~5 min |
| 2.13 | Create Python venv: `python3 -m venv ~/escort-env` | Romeo | [ ] | Isolated from system Python |
| 2.14 | Activate + install requirements: `source ~/escort-env/bin/activate && pip install -r requirements.txt` | Romeo | [ ] | Copy requirements.txt to Pi first |
| 2.15 | Install OpenCV: `sudo apt install python3-opencv` | Romeo | [ ] | System package preferred over pip on Pi |
| 2.16 | Download MobileNet SSD v2 model to Pi: run `install.sh` | Romeo | [ ] | Creates `~/models/` with `.pb` + `.pbtxt` |
| 2.17 | Test Python imports work: `python3 -c "import cv2, numpy, gpiozero; print('OK')"` | Romeo | [ ] | All should import cleanly |
| 2.18 | Set Pi to auto-connect to phone hotspot (backup WiFi) | Romeo | [ ] | `sudo nmcli dev wifi connect "iPhone" password "xxx"` |
| 2.19 | **Alex's Pi:** Repeat steps 2.1–2.17 on Alex's Raspberry Pi | Alex | [ ] | Same OS + software, hostname `elktron-alex` |

---

## PHASE 3: ESCORT BOT — HARDWARE BUILD (March 11–15)

### 3A: Chassis Assembly (~2 hours)

| # | Task | Owner | Status | Notes |
|---|---|---|---|---|
| 3A.1 | Unbox LK-COKOINO kit — lay out all parts, verify nothing missing | Alex | [ ] | Compare against Amazon listing photos |
| 3A.2 | Identify top and bottom chassis plates | Alex | [ ] | Bottom plate = motor mounts |
| 3A.3 | Mount 4 DC motors to bottom plate using brackets + screws | Alex + Raphael | [ ] | Motor shafts face OUTWARD (toward wheels) |
| 3A.4 | Attach 4 wheels to motor shafts | Alex | [ ] | Press fit — should be snug, not loose |
| 3A.5 | Spin each wheel by hand — verify free rotation, no grinding | Alex | [ ] | If grinding: re-seat motor in bracket |
| 3A.6 | Label motors with tape: FL (front-left), FR, RL, RR | Alex | [ ] | Critical for wiring — wrong labels = reversed steering |
| 3A.7 | Mount standoffs between bottom and top plates | Alex | [ ] | 4-6 standoffs, leave clearance for wires between plates |
| 3A.8 | Attach top plate | Alex | [ ] | Don't fully tighten yet — need access for wiring |

### 3B: Motor Wiring (~1 hour)

| # | Task | Owner | Status | Notes |
|---|---|---|---|---|
| 3B.1 | Solder or connect motor leads (2 wires per motor, 8 total) | Alex | [ ] | If no soldering iron: twist + electrical tape works for prototype |
| 3B.2 | Route all motor wires to center of chassis | Alex | [ ] | Where L298N will mount |
| 3B.3 | Wire LEFT motors in parallel: FL red→RL red, FL black→RL black | Alex | [ ] | Result: one wire pair for LEFT side |
| 3B.4 | Wire RIGHT motors in parallel: FR red→RR red, FR black→RR black | Alex | [ ] | Result: one wire pair for RIGHT side |
| 3B.5 | Quick polarity test: touch 7.4V battery briefly to LEFT pair | Alex | [ ] | Wheels should spin FORWARD. If backward: swap wires. |
| 3B.6 | Repeat polarity test for RIGHT pair | Alex | [ ] | Same direction as LEFT |
| 3B.7 | Mount L298N motor driver on top plate | Alex | [ ] | Double-sided tape or standoffs |
| 3B.8 | Connect LEFT motor pair → L298N OUT1 + OUT2 screw terminals | Alex | [ ] | Tighten firmly — loose = intermittent failure |
| 3B.9 | Connect RIGHT motor pair → L298N OUT3 + OUT4 screw terminals | Alex | [ ] | Tighten firmly |
| 3B.10 | Connect 18650 battery holder → L298N +12V (VCC) + GND terminals | Alex | [ ] | **Do NOT insert batteries yet** |
| 3B.11 | **Remove L298N 5V jumper** — Pi gets separate power via USB-C | Alex | [ ] | Jumper OUT = safer, cleaner power |

### 3C: L298N → Pi GPIO Wiring (~30 min)

| # | Task | Owner | Status | Notes |
|---|---|---|---|---|
| 3C.1 | Connect L298N IN1 → Pi GPIO 17 (jumper wire) | Alex | [ ] | Left motor forward |
| 3C.2 | Connect L298N IN2 → Pi GPIO 24 | Alex | [ ] | Left motor backward |
| 3C.3 | Connect L298N IN3 → Pi GPIO 22 | Alex | [ ] | Right motor forward |
| 3C.4 | Connect L298N IN4 → Pi GPIO 23 | Alex | [ ] | Right motor backward |
| 3C.5 | **CRITICAL: Connect L298N GND → Pi GND (pin 6)** | Alex | [ ] | Common ground — without this, motors won't respond to GPIO |
| 3C.6 | Optional: Connect ENA → GPIO 12, ENB → GPIO 13 for PWM speed | Alex | [ ] | If not using: leave jumpers on ENA/ENB for full speed |
| 3C.7 | Double-check all 5 connections against wiring diagram in `WIRING.md` | Alex + Raphael | [ ] | Two sets of eyes — one wrong wire can fry the Pi |
| 3C.8 | Take a photo of the completed wiring | Alex | [ ] | For troubleshooting + documentation |

### 3D: Motor Test (~15 min)

| # | Task | Owner | Status | Notes |
|---|---|---|---|---|
| 3D.1 | Insert 18650 batteries into holder | Alex | [ ] | Charged batteries only |
| 3D.2 | Power on Pi via USB-C power bank | Alex | [ ] | Wait for boot — 30 sec |
| 3D.3 | SSH into Pi | Romeo or Alex | [ ] | `ssh elktron@elktron-escort.local` |
| 3D.4 | Run motor test script: | Romeo | [ ] | See script below |

```python
# motor_test.py — run on Pi
from gpiozero import Robot
import time
robot = Robot(left=(17, 24), right=(22, 23))
print("Forward..."); robot.forward(0.3); time.sleep(2)
print("Stop"); robot.stop(); time.sleep(1)
print("Backward..."); robot.backward(0.3); time.sleep(2)
print("Stop"); robot.stop(); time.sleep(1)
print("Left turn..."); robot.left(0.3); time.sleep(2)
print("Stop"); robot.stop(); time.sleep(1)
print("Right turn..."); robot.right(0.3); time.sleep(2)
print("Stop"); robot.stop()
print("DONE — all 4 directions tested")
```

| # | Task | Owner | Status | Notes |
|---|---|---|---|---|
| 3D.5 | Verify forward: all 4 wheels spin forward | Alex | [ ] | Prop chassis on box so wheels are off ground |
| 3D.6 | Verify backward: all 4 wheels spin backward | Alex | [ ] | |
| 3D.7 | Verify left turn: right wheels forward, left slow/reverse | Alex | [ ] | If reversed: swap LEFT/RIGHT pairs on L298N |
| 3D.8 | Verify right turn: left wheels forward, right slow/reverse | Alex | [ ] | |
| 3D.9 | If any direction wrong: check wiring, swap motor pair wires | Alex | [ ] | Most common issue: forward/backward swapped on one side |

### 3E: Ultrasonic Sensor (HC-SR04) (~30 min)

| # | Task | Owner | Status | Notes |
|---|---|---|---|---|
| 3E.1 | Build voltage divider on breadboard: ECHO → 1kΩ → junction → 2kΩ → GND | Alex or Raphael | [ ] | Junction point connects to GPIO 24 |
| 3E.2 | Connect HC-SR04 VCC → Pi 5V (pin 2) | Alex | [ ] | |
| 3E.3 | Connect HC-SR04 GND → Pi GND | Alex | [ ] | |
| 3E.4 | Connect HC-SR04 TRIG → GPIO 25 | Alex | [ ] | |
| 3E.5 | Connect voltage divider junction → GPIO 24 | Alex | [ ] | **Do NOT connect ECHO directly to Pi — 5V will damage it** |
| 3E.6 | Mount HC-SR04 on front of chassis, facing forward | Alex | [ ] | Hot glue, velcro, or mounting bracket |
| 3E.7 | Run ultrasonic test: | Romeo | [ ] | See script below |

```python
# sonar_test.py — run on Pi
from gpiozero import DistanceSensor
import time
sonar = DistanceSensor(echo=26, trigger=25, max_distance=2)
for i in range(20):
    print(f"Distance: {sonar.distance * 100:.1f} cm")
    time.sleep(0.5)
```

| # | Task | Owner | Status | Notes |
|---|---|---|---|---|
| 3E.8 | Hold hand at 30cm → reading ~30cm (±5cm) | Alex | [ ] | |
| 3E.9 | Hold hand at 100cm → reading ~100cm | Alex | [ ] | |
| 3E.10 | Remove hand → reading >150cm | Alex | [ ] | |
| 3E.11 | If readings always 0 or max: check voltage divider wiring | Alex | [ ] | Most common issue |

### 3F: Camera + Pan-Tilt Mount (~1 hour, after 3/12 delivery)

| # | Task | Owner | Status | Notes |
|---|---|---|---|---|
| 3F.1 | Assemble Arducam pan-tilt platform (2 servos + bracket) | Alex or Raphael | [ ] | Follow Arducam instructions |
| 3F.2 | Mount pan-tilt on TOP of chassis using standoffs or bracket | Alex | [ ] | Needs to be stable — camera shake ruins detection |
| 3F.3 | Connect pan-tilt servo controller to Pi (I2C or GPIO PWM) | Alex | [ ] | Check Arducam docs for pin assignment |
| 3F.4 | Mount camera on pan-tilt bracket | Alex | [ ] | Camera arrives 3/14 — use USB webcam for testing until then |
| 3F.5 | Connect Arducam IMX708 via CSI ribbon cable to Pi 5 | Alex | [ ] | Pi 5 has different CSI connector than Pi 4 — use correct cable |
| 3F.6 | Test camera: `libcamera-hello --timeout 5000` | Romeo | [ ] | Should show live preview |
| 3F.7 | Test pan-tilt servos sweep (write quick test script) | Romeo | [ ] | Pan: ±45°, Tilt: -30° to +60° |
| 3F.8 | Verify 120° FOV captures full aisle width at 2m distance | Alex | [ ] | Stand 2m away, walk side to side — should stay in frame |

### 3G: Mast Construction (~30 min, Home Depot parts)

| # | Task | Owner | Status | Notes |
|---|---|---|---|---|
| 3G.1 | Cut PVC pipe to ~3.5 ft (adjust based on chassis height) | Anyone | [ ] | Goal: camera at mid-rack height (~3-4 ft from floor) |
| 3G.2 | Attach PVC T-connector to base of mast | Anyone | [ ] | T-connector mounts horizontally to chassis |
| 3G.3 | Secure T-connector to chassis with zip ties or bolts | Anyone | [ ] | Must be rigid — wobble = unusable camera feed |
| 3G.4 | Mount pan-tilt + camera at top of mast | Alex | [ ] | Velcro + zip ties — needs to be removable for transport |
| 3G.5 | Route CSI ribbon cable down mast, secure with velcro | Alex | [ ] | Keep away from motor wires — EMI interference |
| 3G.6 | Stability test: push mast gently — should not sway more than 1cm | Alex | [ ] | If wobbly: add cross-brace with PVC elbow |

### 3H: Power System Assembly (~30 min)

| # | Task | Owner | Status | Notes |
|---|---|---|---|---|
| 3H.1 | Insert charged 18650 batteries into battery holder | Alex | [ ] | 2 batteries in series = 7.4V for motors |
| 3H.2 | Connect battery holder to L298N VCC + GND | Alex | [ ] | Already done in 3B.10 |
| 3H.3 | Connect USB-C power bank to Pi 5 via short USB-C cable | Alex | [ ] | Mount power bank on chassis with velcro |
| 3H.4 | Verify Pi boots on battery power (not wall plug) | Alex | [ ] | Green LED blinks, SSH works |
| 3H.5 | Verify motors spin on battery power | Alex | [ ] | Run motor_test.py again |
| 3H.6 | Run full system for 5 min — check for brown-outs | Alex | [ ] | If Pi reboots: power bank can't supply enough amps |
| 3H.7 | Measure battery life: run motors continuously, time until weak | Alex | [ ] | Target: 30+ min for demo day |
| 3H.8 | Label all power connections with tape | Alex | [ ] | So you can swap batteries quickly on demo day |

---

## PHASE 4: ESCORT BOT — SOFTWARE TESTING (March 12–16)

### 4A: Camera-Only Detection (no motors needed)

| # | Task | Owner | Status | Notes |
|---|---|---|---|---|
| 4A.1 | Copy `test_camera.py` to Pi: `scp test_camera.py elktron@elktron-escort.local:~/` | Romeo | [ ] | |
| 4A.2 | Run: `python3 test_camera.py` (headless mode) | Romeo | [ ] | Terminal output: "Person detected at (x,y) conf=0.XX" |
| 4A.3 | Stand 1m from camera → verify person detection confidence >0.5 | Romeo | [ ] | |
| 4A.4 | Stand 3m from camera → verify still detects (may be lower confidence) | Romeo | [ ] | |
| 4A.5 | Walk side to side → verify bounding box tracks correctly | Romeo | [ ] | |
| 4A.6 | Test with 2 people in frame → should track the largest (closest) | Romeo + anyone | [ ] | |
| 4A.7 | Check inference speed: should be <100ms per frame on Pi 5 | Romeo | [ ] | If >200ms: check model is quantized (uint8) |
| 4A.8 | Test in different lighting: bright, dim, fluorescent | Romeo | [ ] | DC floor is fluorescent — test under similar lighting |
| 4A.9 | Test with person in dark clothing | Romeo | [ ] | Common failure mode |
| 4A.10 | Test with person carrying a box (partial occlusion) | Romeo | [ ] | Vendor escort scenario |

### 4B: Full Software Integration (after motors + sonar tested)

| # | Task | Owner | Status | Notes |
|---|---|---|---|---|
| 4B.1 | Copy `main.py` + `pan_tilt.py` to Pi | Romeo | [ ] | |
| 4B.2 | Edit `main.py` config: verify GPIO pins match wiring | Romeo | [ ] | LEFT_MOTOR, RIGHT_MOTOR, ECHO, TRIG |
| 4B.3 | Edit camera config: verify resolution + camera index | Romeo | [ ] | Use picamera2 for Arducam IMX708 |
| 4B.4 | Edit model path: verify `models/ssd_mobilenet_v2.pb` exists | Romeo | [ ] | |
| 4B.5 | **Bench test (wheels off ground):** run `main.py` | Romeo + Alex | [ ] | See checklist below |
| 4B.6 | Stand in front → wheels spin forward | Alex observes | [ ] | |
| 4B.7 | Move LEFT → right wheels speed up (bot tries to turn left) | Alex observes | [ ] | |
| 4B.8 | Move RIGHT → left wheels speed up (bot turns right) | Alex observes | [ ] | |
| 4B.9 | Walk closer → wheels slow down / stop (too close) | Alex observes | [ ] | |
| 4B.10 | Walk away → wheels speed up (trying to follow) | Alex observes | [ ] | |
| 4B.11 | Disappear from frame → wheels stop after 1.5 sec | Alex observes | [ ] | |
| 4B.12 | Hold hand in front of sonar (<30cm) → emergency stop | Alex observes | [ ] | |
| 4B.13 | If steering reversed: swap left/right GPIO in config | Romeo | [ ] | |
| 4B.14 | Test scan mode: stand still for 3+ seconds → scan triggers | Romeo | [ ] | Pan-tilt should sweep, capture frames to `scans/` |

### 4C: Floor Testing (after bench test passes)

| # | Task | Owner | Status | Notes |
|---|---|---|---|---|
| 4C.1 | Find open indoor space (hallway, garage, empty room) | Anyone | [ ] | Smooth floor, not carpet |
| 4C.2 | Set `BASE_SPEED = 0.2` (start slow) | Romeo | [ ] | Safety first |
| 4C.3 | Place bot on floor, SSH in, run `main.py` | Romeo | [ ] | |
| 4C.4 | **Safety:** Someone stands near bot ready to pick it up | Alex or Raphael | [ ] | |
| 4C.5 | Stand 2m in front → bot moves toward you | Romeo | [ ] | |
| 4C.6 | Walk forward slowly → bot follows | Romeo | [ ] | |
| 4C.7 | Stop → bot stops within 0.5–1m | Romeo | [ ] | |
| 4C.8 | Turn left → bot turns left | Romeo | [ ] | |
| 4C.9 | Turn right → bot turns right | Romeo | [ ] | |
| 4C.10 | Walk behind a pillar/wall → bot stops after timeout | Romeo | [ ] | |
| 4C.11 | Walk for 30+ seconds continuously → bot follows the whole time | Romeo | [ ] | THIS is the demo shot |
| 4C.12 | Record a phone video of the floor test | Anyone | [ ] | Good for demo B-roll |

### 4D: Tuning (~1 hour, iterate on these)

| # | Task | Owner | Status | Notes |
|---|---|---|---|---|
| 4D.1 | If oscillating left/right: reduce KP (1.0 → 0.6) | Romeo | [ ] | |
| 4D.2 | If not turning enough: increase KP (1.0 → 1.5) | Romeo | [ ] | |
| 4D.3 | If following too close: decrease TARGET_AREA_RATIO (0.15 → 0.10) | Romeo | [ ] | |
| 4D.4 | If too far: increase TARGET_AREA_RATIO (0.15 → 0.20) | Romeo | [ ] | |
| 4D.5 | If losing person too easily: decrease CONFIDENCE_THRESHOLD (0.5 → 0.35) | Romeo | [ ] | |
| 4D.6 | If tracking wrong objects: increase CONFIDENCE_THRESHOLD | Romeo | [ ] | |
| 4D.7 | Gradually increase BASE_SPEED (0.2 → 0.3 → 0.4 → 0.5) | Romeo | [ ] | |
| 4D.8 | Record final "golden config" values — write them in main.py | Romeo | [ ] | These are the demo settings |

---

## PHASE 5: SO-101 ARM BUILD (March 18–21, after kit arrives)

### 5A: Assembly (~2-3 hours)

| # | Task | Owner | Status | Notes |
|---|---|---|---|---|
| 5A.1 | Unbox HiWonder kit — inventory all parts against list | Josh + Talha | [ ] | 2 arms, 12 servos, 2 BusLinkers, PSUs, clamps, hardware |
| 5A.2 | Verify all 12 servos spin freely — none DOA | Josh | [ ] | Power each briefly to test |
| 5A.3 | **Leader arm assembly:** mount servos S1-S6 (base → gripper) | Josh | [ ] | Follow HiWonder assembly guide |
| 5A.4 | Route leader arm cables, velcro at each joint | Josh | [ ] | Clean routing prevents snags |
| 5A.5 | Connect leader servos to BusLinker V3.0 (daisy chain) | Josh | [ ] | |
| 5A.6 | Connect 5V PSU to leader BusLinker | Josh | [ ] | |
| 5A.7 | Connect USB-C from leader BusLinker to laptop | Josh | [ ] | Verify detected: `ls /dev/ttyACM*` or `ls /dev/cu.usbmodem*` |
| 5A.8 | **Follower arm assembly:** repeat S1-S6 (identical to leader) | Josh + Talha | [ ] | |
| 5A.9 | Route follower cables, velcro at joints | Josh + Talha | [ ] | |
| 5A.10 | Connect follower servos to BusLinker V3.0 | Josh | [ ] | |
| 5A.11 | Connect 12V 5A PSU to follower BusLinker | Josh | [ ] | Higher voltage = more torque |
| 5A.12 | Connect USB-C from follower BusLinker to laptop | Josh | [ ] | Should be second ttyACM device |
| 5A.13 | Clamp both arms to table ~30cm apart | Josh | [ ] | Firm — no wobble allowed |
| 5A.14 | Mount NexiGo webcam overhead or on gooseneck, pointing at follower workspace | Josh | [ ] | Verify webcam sees full arm workspace |

### 5B: Mechanical Verification (~30 min)

| # | Task | Owner | Status | Notes |
|---|---|---|---|---|
| 5B.1 | Manually move each leader arm joint — smooth, no binding | Josh | [ ] | |
| 5B.2 | Manually move each follower arm joint — smooth, no binding | Josh | [ ] | |
| 5B.3 | Verify gripper opens/closes fully on both arms | Josh | [ ] | |
| 5B.4 | Confirm full range of motion — no table collisions | Josh | [ ] | |
| 5B.5 | Tighten all screws — loose screws = drift during training | Josh | [ ] | |
| 5B.6 | Verify cable routing doesn't snag during full sweep | Josh | [ ] | |

### 5C: Software Setup (~1 hour)

| # | Task | Owner | Status | Notes |
|---|---|---|---|---|
| 5C.1 | Install Python 3.11 on training machine (Mac or Linux laptop) | Josh | [ ] | |
| 5C.2 | Create venv: `python3 -m venv ~/lerobot-env` | Josh | [ ] | |
| 5C.3 | Run `so101/install.sh` — installs LeRobot + deps | Josh | [ ] | |
| 5C.4 | Verify torch backend: `torch.backends.mps.is_available()` (Mac) | Josh | [ ] | |
| 5C.5 | Create LeRobot config YAML — set serial ports + camera index | Josh | [ ] | follower: ttyACM0, leader: ttyACM1, camera: 0 |
| 5C.6 | Test config loads: `python -c "from lerobot..."` | Josh | [ ] | |
| 5C.7 | Test webcam: `python -c "import cv2; cap=cv2.VideoCapture(0); print(cap.read()[0])"` | Josh | [ ] | |

### 5D: Calibration (~1 hour)

| # | Task | Owner | Status | Notes |
|---|---|---|---|---|
| 5D.1 | Run LeRobot calibration: `python lerobot/scripts/control_robot.py calibrate` | Josh | [ ] | Move each joint to physical limits when prompted |
| 5D.2 | Record min/max angles for all 6 joints, both arms | Josh | [ ] | Write down on paper |
| 5D.3 | Save calibration file — back it up | Josh | [ ] | **Do NOT lose this** |
| 5D.4 | Test mirroring: move leader joint 1 to 90° → follower matches | Josh | [ ] | |
| 5D.5 | Test all 6 joints mirror within ~2° | Josh | [ ] | |
| 5D.6 | Mark workspace positions with tape: HOME, OPTIC TRAY, SWITCH PORT | Josh | [ ] | |
| 5D.7 | Verify follower can reach: home → tray → port → home | Josh | [ ] | |

### 5E: Teleoperation + Data Collection (~2-3 hours)

| # | Task | Owner | Status | Notes |
|---|---|---|---|---|
| 5E.1 | Launch teleoperation mode — verify leader controls follower | Josh | [ ] | |
| 5E.2 | Practice optic seating manually 5+ times before recording | Josh | [ ] | Grab optic → lift → move to port → seat → release → retract |
| 5E.3 | Start recording: `python so101/record.py` | Josh | [ ] | |
| 5E.4 | Record episodes 1–10 (basic, clean motions) | Josh | [ ] | Each episode: 10–30 seconds |
| 5E.5 | Review episode 1 video — camera captures full action? | Josh | [ ] | |
| 5E.6 | Record episodes 11–30 (consistent, smooth) | Josh + Talha | [ ] | Talha can take turns recording |
| 5E.7 | Record episodes 31–50 (add minor variations: angle, path) | Josh + Talha | [ ] | |
| 5E.8 | Verify dataset: video files exist, joint CSVs look correct | Josh | [ ] | |
| 5E.9 | Delete any episodes with collisions or drops | Josh | [ ] | |
| 5E.10 | Backup dataset to external drive or cloud | Josh | [ ] | |
| 5E.11 | **Stretch:** Record 50+ more episodes for robustness | Josh + Talha | [ ] | 100 total is ideal |
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

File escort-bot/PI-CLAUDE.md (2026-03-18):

# Escort Bot — Raspberry Pi 5 Context

You are Claude Code running directly on a **Raspberry Pi 5 (8GB)** inside a mobile robot called the **Escort Bot**. This is one of two robots in the **Elktron** hackathon project for **CoreWeave's "More. Better. Faster." hackathon** (March 23–25, 2026 · Demo Day: March 26).

---
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

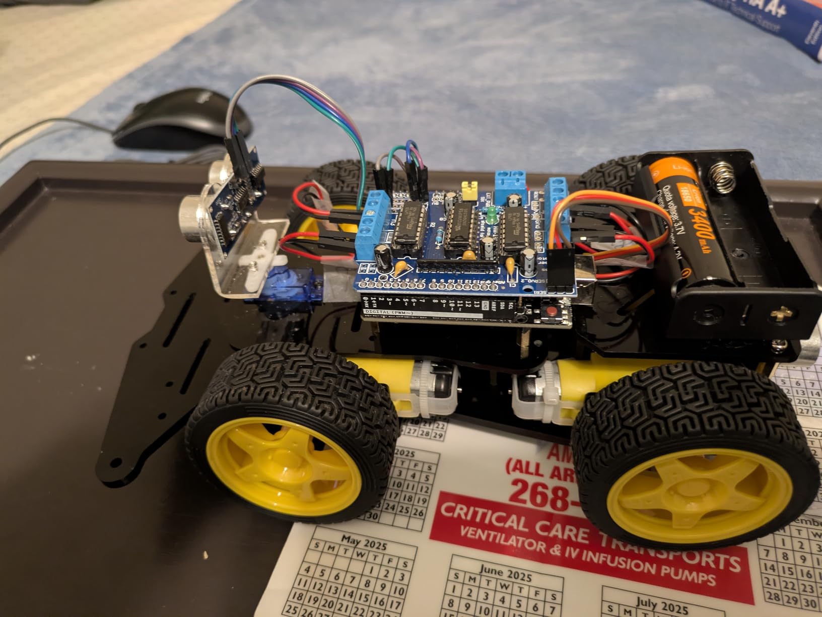
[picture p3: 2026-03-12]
reference/chassis-photos/car4.jpg

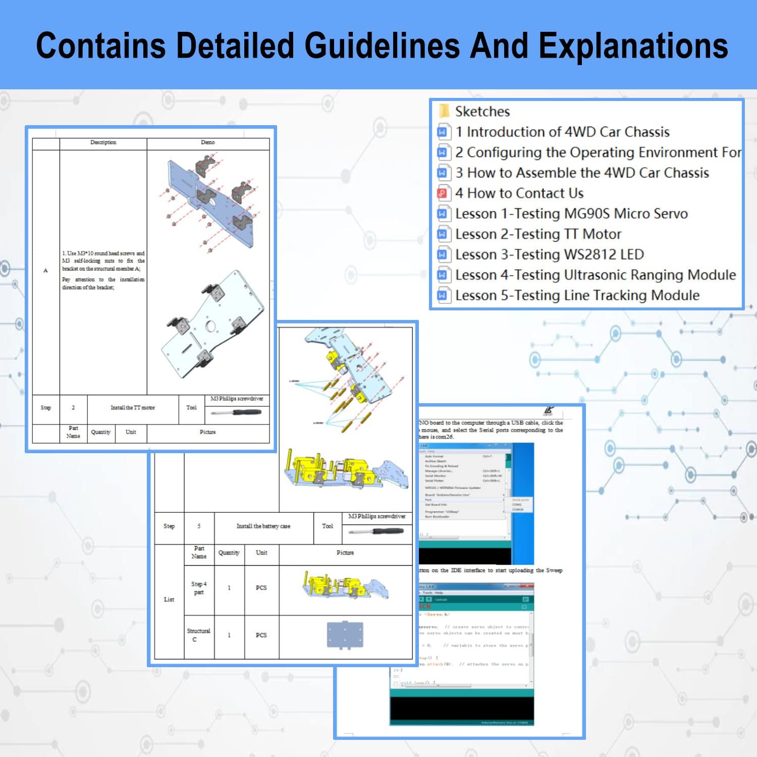
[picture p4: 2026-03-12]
reference/chassis-photos/car_wire_diagram.jpg

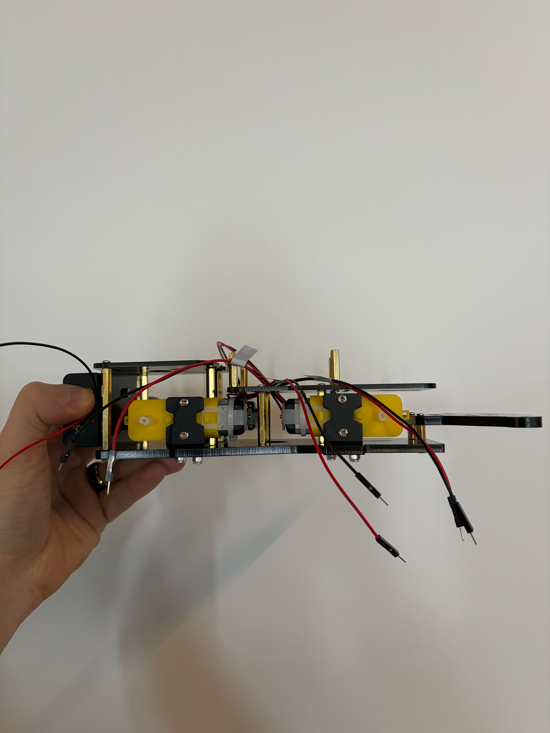
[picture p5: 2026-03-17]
reference/chassis-photos/chassis_side_left.jpg

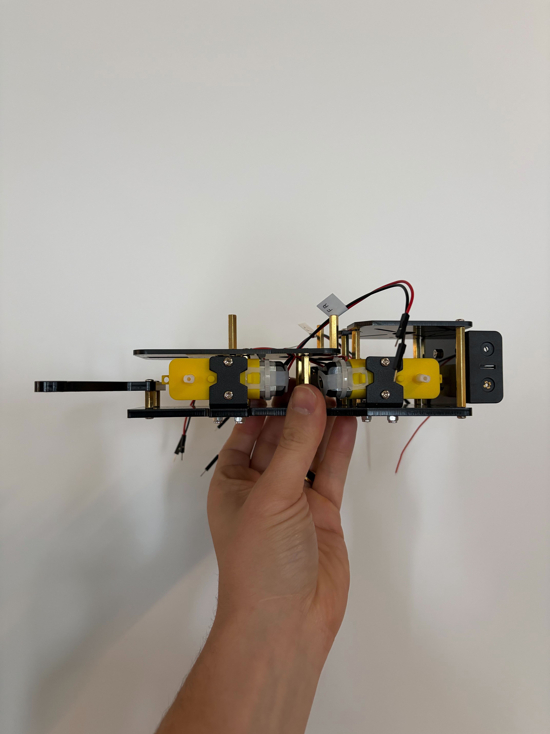
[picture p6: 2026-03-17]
reference/chassis-photos/chassis_side_right.jpg

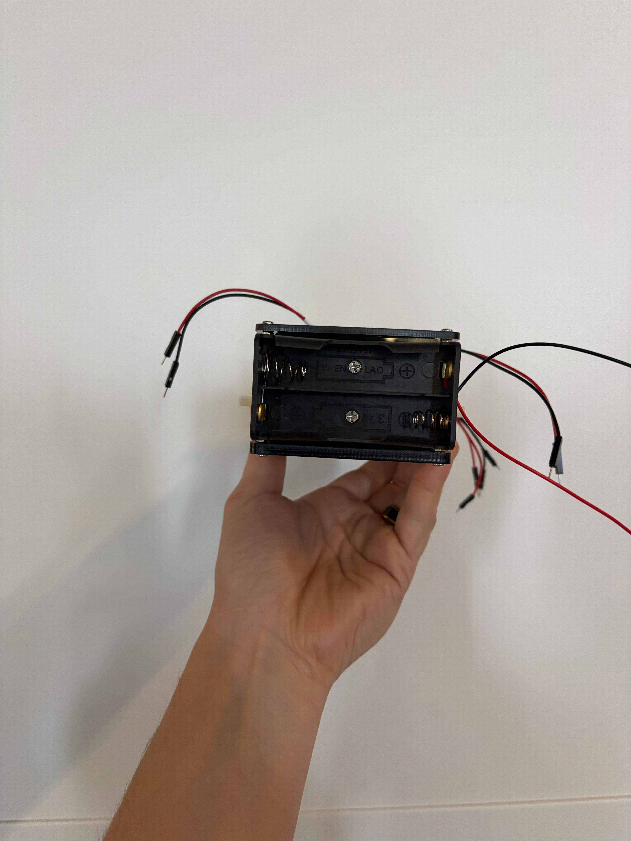
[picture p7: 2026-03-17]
reference/chassis-photos/chassis_battery_holder.jpg

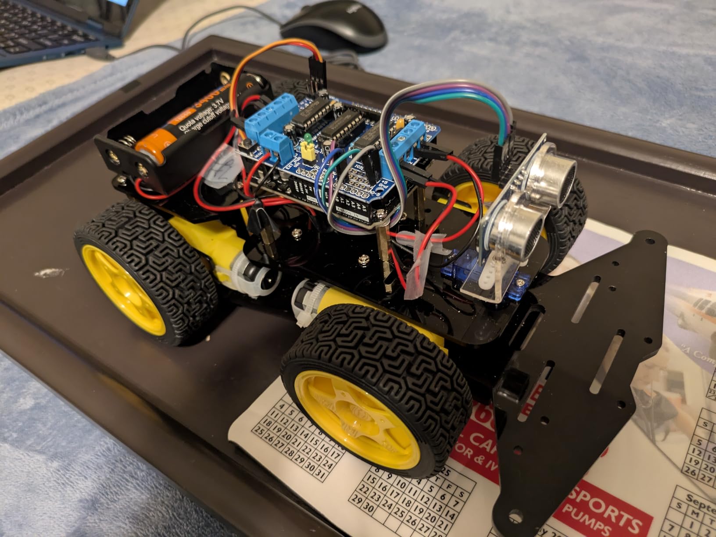
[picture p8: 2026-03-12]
reference/chassis-photos/car_6.jpg

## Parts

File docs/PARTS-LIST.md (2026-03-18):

# Elktron — Complete Parts List

> **Last updated:** 2026-03-12
> **Budget estimate:** ~$430–$455 total (before owned items)
> **Hackathon:** March 23–25, 2026 · **Demo Day:** March 26

Legend: ✅ = Owned | 🛒 = Need to buy | ⏳ = Ordered, waiting

---

## ROBOT 1: SO-101 Arm (Manipulation Bot)

### Option A: HiWonder Pre-Built Kit (RECOMMENDED)

- [ ] 🛒 **SO-ARM101 DIY Kit** — ~$270
  - Source: https://www.hiwonder.com/products/lerobot-so-101
  - Includes ALL of the following:
    - 6x Follower arm servos (HX-30HM / STS3215) — 30kg.cm @ 12V
    - 6x Leader arm servos (HX-10HM) — lighter, for teleoperation
    - 2x BusLinker V3.0 servo controller (USB-to-serial)
    - 1x 12V 5A power supply (barrel jack, follower arm)
    - 1x 5V power supply (leader arm)
    - 4x Table clamps (2 per arm)
    - Full set 3D-printed structural parts (ABS/PLA arm links + brackets)
    - Screws, cables, assembly hardware (M2/M3)

### Option B: DIY Build (requires 3D printer)

- [ ] 🛒 Feetech STS3215 servos x6 (follower) — ~$120 — AliExpress / RobotShop
- [ ] 🛒 Feetech STS3215 servos x6 (leader) — ~$100 — AliExpress
- [ ] 🛒 BusLinker V3.0 board x2 — ~$30 — HiWonder / AliExpress
- [ ] 🛒 3D-printed parts (STLs from https://github.com/TheRobotStudio/SO-ARM100) — ~$35 filament
- [ ] 🛒 12V 5A DC power supply — ~$12 — Amazon
- [ ] 🛒 5V 3A power supply — ~$8 — Amazon
- [ ] 🛒 Table C-clamps x4 (2" opening min) — ~$10 — Amazon / hardware store
- [ ] 🛒 M2 + M3 screw assortment kit — ~$8 — Amazon
- [ ] 🛒 Servo extension cables x6 (3-pin, 20cm) — ~$5 — Amazon

### Arm Add-ons (needed regardless of option)

- [ ] 🛒 **USB webcam (arm-mounted)** — ~$25 — Logitech C270 or similar, 1080p, OpenCV-compatible
- [ ] 🛒 USB-C data cable (to laptop, 6ft) — ~$8 — Amazon
- [ ] 🛒 Webcam mount/bracket — ~$5 — 3D-print or flex gooseneck clamp
- [ ] 🛒 Velcro cable ties / strips — ~$5 — Amazon (reusable, easier to reposition during prototyping)

**Arm subtotal (Option A + add-ons): ~$311**

---

## ROBOT 2: Escort Bot (Person-Following Mobile Robot)

### Compute (OWNED)

- [x] ✅ **Raspberry Pi 5** (8GB) — Alex has it (bringing to build sessions)
- [x] ✅ **Raspberry Pi 4** — OWNED by Romeo (backup)
- [x] ✅ **Raspberry Pi Pico** — OWNED by Romeo (not ideal for CV)
- [x] ✅ **MicroSD card** — OWNED by Romeo
- [x] ✅ **Raspberry Pi 5 Active Cooler (OFFICIAL)** — DELIVERED 3/11
  - PWM temp-controlled blower + aluminum heatsink + thermal tape
  - REQUIRED — CV inference workload will thermal throttle Pi 5 without cooling

> **Pi 5 OS Setup Guide:** See [`escort-bot/PI-SETUP.md`](../escort-bot/PI-SETUP.md)
> **OS:** Raspberry Pi OS Lite (64-bit) — Bookworm. Only official OS for Pi 5. Lite = headless, no desktop wasting RAM.
> **Imager download:** https://downloads.raspberrypi.com/imager/imager_latest.dmg

### Chassis + Drivetrain

- [x] ✅ **LK-COKOINO 4WD Chassis Kit** — $26.99 — Alex ordering
  - Amazon: https://www.amazon.com/Arduino-LK-COKOINO-Raspberry-Building/dp/B0B5JPJ9R4
  - Kit includes (BARE CHASSIS ONLY):
    - Acrylic frame pieces
    - 4x TT DC geared motors + dupont wires
    - 4x metal motor brackets
    - 4x wheels (rubber, 2.56" diameter)
    - 1x 18650 battery holder (2-slot)
    - Screws, nuts, copper standoffs, zip ties
    - Screwdriver + wrench
  - **NOT included:** motor driver, sensors, camera, servos, Pi, batteries
  - **Docs:** `CKK0011-main/` — assembly PDFs, wiring tutorials

### Motor Control

- [x] ✅ **L298N motor driver (2-pack)** — **DELIVERED 3/12** — $6.98
  - WWZMDiB 2x L298N DC Dual H-Bridge — have a spare
  - Wiring: GPIO 17/27 (left motor), 22/23 (right motor). See WIRING.md.
- [ ] 🛒 Jumper wires M-F x20 (20cm) — ~$5 — Amazon (GPIO → L298N)
- [ ] 🛒 Jumper wires M-M x10 (20cm) — ~$3 — Amazon

### Sensors

- [x] ✅ **HC-SR04 ultrasonic sensors** — DIYables **DELIVERED 3/12** ($6.99), ELEGOO arriving 3/13 ($8.99)
  - DIYables 2-pack (delivered) + ELEGOO 5-pack (arriving 3/13) — plenty of spares
  - ⚠️ ECHO pin is 5V — needs voltage divider (1kΩ + 2kΩ) or use HC-SR04P
- [ ] 🛒 Resistor kit (1kΩ + 2kΩ for voltage divider) — ~$3 — Amazon

### Vision

- [x] ✅ **Arducam Camera Module 3 Wide (IMX708, 120°)** — ORDERED 3/10, arriving Saturday 3/15 — $59.99
  - Autofocus, Pi 5 compatible, includes 15cm 15-22 pin FFC cable + acrylic case
- [x] ✅ **Arducam Pan/Tilt Platform** — **DELIVERED 3/12** — $26.99
  - Compatible with Pi Camera Module 3/V1/V2
  - Pan on GPIO 12, tilt on GPIO 13. Controlled by `pan_tilt.py`.
- [x] ✅ **Arducam Camera Ribbon Flex Extension Cable Set (7pc)** — ORDERED 3/17, arriving 3/18 — $10.71
  - Amazon: https://www.amazon.com/dp/B07SM6JTTM
  - Lengths: 2.87", 5.9", 5.91", 7.87", 11.8", 19.69", 39.37" (~3ft+)
  - Longest cable (39.37") for running CSI from Pi base up PVC mast to camera
  - Includes 15-pin and 22-pin widths (Pi 5 uses 22-pin)

### Power (ALL PORTABLE — no wall outlets on DC floor)

- [x] ✅ **18650 Li-ion batteries (4-pack)** — $22.98 — ORDERED 3/11, arriving Saturday 3/15
  - QOJH 3.7V 3000mAh, button top, protected
  - WHY 4-PACK: 2 in the bot, 2 charged and ready to hot-swap during demo
- [x] ✅ **18650 dual-slot charger** — $8.59 — ORDERED 3/11, arriving Saturday 3/15
  - ACEBOTT smart charger, auto-shutoff, US plug
  - CHARGE NIGHT BEFORE DEMO — full charge takes ~4 hours
- [x] ✅ **18650 battery holder bundle (8-pack)** — **DELIVERED 3/12** — $9.99
  - QTEATAK — 1-slot (3.7V), 2-slot (7.4V), 3-slot (11.1V), 4-slot (14.8V) — 2 of each
  - Gives flexibility if chassis holder breaks or need different voltage configs
- [x] ✅ **USB-C power bank (Pi power)** — $21.99 — ORDERED 3/11, arriving 3/13
  - Anker PowerCore 10K, 10000mAh, 5V/3A USB-C
  - MUST support 5V/3A output — Pi 5 will brownout on weak banks
  - Runtime: ~3-4 hours continuous CV workload
- [ ] 🛒 **Second USB-C power bank (backup/swap)** — ~$22
  - Same model. Demo runs 2-5pm — one bank may not last. Swap takes 10 seconds.
- [ ] 🛒 Short USB-C cable (6-12 inches, power bank → Pi) — ~$5 — Amazon
- [x] ✅ **USB-C right-angle adapter (2-pack)** — $8.49 — **DELIVERED 3/12**
  - Silkland 90° adapter, 240W/40Gbps — overkill specs but keeps cable flush on chassis
- [x] ✅ **CanaKit 3.5A Pi Power Supply with PiSwitch** — $12.99 — **DELIVERED 3/12**
  - Wall adapter with inline on/off switch — USE FOR BENCH TESTING + DEVELOPMENT
  - NOT portable — still need USB-C power bank for untethered DC floor demo

### Power — SO-101 Arm (Demo Day)

- [ ] 🛒 **Extension cord / power strip** — ~$0 (bring from home)
  - The arm's 12V/5V power supplies need wall power — arm is NOT portable
  - Confirm demo area has outlets or bring a 20ft extension cord

**Power architecture (escort bot — fully portable):**
```
Pi 5       ← USB-C power bank (5V/3A, mounted on chassis)
Motors     ← 18650 x2 in series (7.4V) through L298N
Sensors    ← Pi 5V rail (HC-SR04 VCC)
Pan/Tilt   ← Pi 5V rail (2x MG90S servos, ~150mA each)
Camera     ← Pi CSI port (powered by Pi internally)
CRITICAL   → Common GND between Pi and L298N!
```

**Power checklist for demo day:**
- [ ] All 4x 18650s fully charged night before
- [ ] Both power banks fully charged night before
- [ ] Test runtime: time how long the bot runs on one set of batteries
- [ ] Bring the 18650 charger to venue (charge spares during other demos)
- [ ] Extension cord for SO-101 arm wall power

### Mast (Camera Height — CRITICAL for Rack Scans)

- [ ] 🛒 **1" Schedule 40 PVC pipe, 3-4 ft** — ~$3 — Home Depot
  - Raises camera from chassis height (~4") to mid-rack height (~36-48")
  - Without this, camera only sees bottom 2-3 rack units — rack scans useless
  - Cut to length at Home Depot (free cuts)
- [ ] 🛒 **1" PVC T-connector x1** — ~$1 — Home Depot
  - Mounts pipe vertically to chassis frame
  - Horizontal arm bolts/zip-ties to acrylic frame mounting holes
- [ ] 🛒 **1" PVC elbow x1** — ~$1 — Home Depot
  - Top of mast — angles camera toward rack face
  - Pan/tilt platform mounts here
- [ ] 🛒 **1" PVC end cap x1** — ~$0.50 — Home Depot
  - Bottom of T-connector, optional stability
- [ ] 🛒 **PVC cement (small can)** — ~$4 — Home Depot
  - Glues T-connector and elbow permanently
  - OR skip cement and use friction fit + zip ties (faster, adjustable during prototyping)
- [ ] 🛒 **Hose clamps x2 (1" diameter)** — ~$2 — Home Depot
  - Secures PVC T-connector to chassis frame
  - Alternative: heavy-duty zip ties through chassis mounting holes

### Misc Hardware

- [ ] 🛒 Velcro strips / cable ties (reusable) — ~$5
- [ ] 🛒 Double-sided foam tape (1 roll) — ~$5
- [ ] 🛒 Half-size breadboard — ~$4
- [ ] 🛒 Electrical tape (1 roll) — ~$3
- [ ] 🛒 Heat shrink tubing assortment — ~$5 — Home Depot / Amazon (for voltage divider solder joints, cleaner than tape)
- [ ] 🛒 Rubber bumper pads (self-adhesive) — ~$3 — Home Depot (chassis corner protection for demo day)
- [ ] Rubber bands x5 — ~$0 (around the house)

**Escort bot subtotal: ~$202** (chassis from Alex, all electronics bought separately — L298N, HC-SR04, camera, pan/tilt, power, mast)

---

## SHARED / DEMO EQUIPMENT

- [x] ✅ **Laptop** (Mac M-series for training + demo) — OWNED
- [ ] 🛒 USB-A hub (4-port, if laptop is USB-C only) — ~$12 — Amazon
- [ ] 🛒 Ethernet cable (for SSH into Pi) — ~$5 — Amazon
- [ ] 🛒 HDMI cable + portable monitor (optional, Pi debug) — ~$0-30
- [ ] 🛒 **Extension cord (25ft)** — ~$10 — Home Depot / Amazon
  - SO-101 arm needs wall power (12V + 5V supplies). Demo area may not have outlets nearby.
- [ ] 🛒 **Power strip (6-outlet, surge protector)** — ~$10 — Amazon
  - Arm 12V supply + arm 5V supply + laptop charger + 18650 charger (charging spares during demo)
- [ ] Sample optic / fiber tray (arm demo task) — grab from DC floor
- [ ] Hard hat / safety vest (demo realism) — already have from DC

**Shared subtotal: ~$37-67**

---

## COST SUMMARY

| Category | Estimate |
|---|---|
| SO-101 Arm (HiWonder kit + add-ons) | ~$311 |
| Escort Bot (all parts — kit covers driver/sensor/camera) | ~$175 |
| Shared / Demo gear | ~$37-67 |
| **GRAND TOTAL** | **~$523-553** |
| Minus owned items (Pi 5, Pi 4, laptop, DC gear) | -$0 saved (no price on owned) |

### Savings:
- Alex providing chassis kit (~$27 saved)
- CanaKit PiSwitch replaces standalone power switch (~$7 saved)

---

## ORDER PRIORITY (what to buy first)

1. **HiWonder SO-101 Kit** — longest ship time (~5-7 days), order ASAP
2. **Freenove 4WD Kit** — Amazon Prime, 1-2 days
3. **Batteries + charger** — need charged before demo day
4. **Everything else** — Amazon Prime, order by March 18 latest

---

## RESOURCE LINKS

| Resource | URL |
|---|-----|
| HiWonder SO-101 Kit | https://www.hiwonder.com/products/lerobot-so-101 |
| SO-ARM100 STLs (3D print) | https://github.com/TheRobotStudio/SO-ARM100 |
| LeRobot (HuggingFace) | https://github.com/huggingface/lerobot |
| LeRobot SO-101 docs | https://huggingface.co/docs/lerobot/en/so101 |
| Freenove 4WD GitHub | https://github.com/Freenove/Freenove_4WD_Smart_Car_Kit_for_Raspberry_Pi |
| Haoran Xu build log | https://www.linkedin.com/pulse/lets-build-ai-hack-lerobot-so101-haoran-xu-onaqc/ |
| iRobot Create 3 (alt escort) | https://github.com/iRobotEducation/create3_docs |

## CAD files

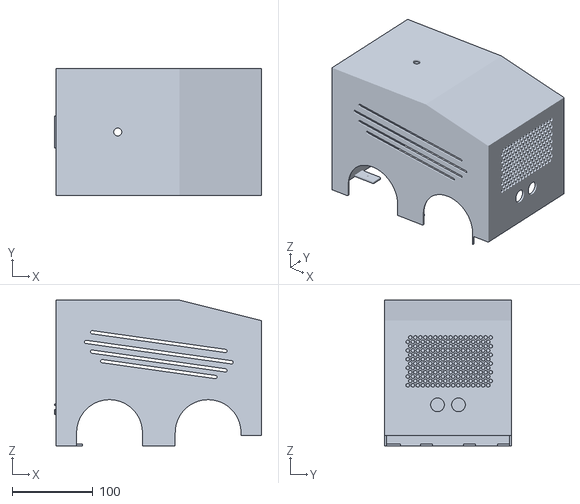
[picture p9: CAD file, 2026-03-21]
escort-bot/shell.stl
256.0 x 157.4 x 180.3

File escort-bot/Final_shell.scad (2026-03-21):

// ============================================
// ESCORT BOT SHELL — v5 from scratch
// ============================================
// Built piece by piece from Romeo's measurements
// ============================================

// --- SIDE PANEL ---
panel_l   = 254;     // 10" long
panel_h   = 177.8;   // 7" tall
wall      = 2.5;     // wall thickness
panel_gap = 152.4;   // 6" between panels

// --- WHEEL ARCHES ---
arch_w     = 81.28;         // ~3.2" wide (gap between arches shrunk 20% total)
arch_h     = 57.15;         // 2.25" tall (shortened — fender raise covers bottom)
arch_r     = arch_w / 2;    // semicircle radius
tire_gap   = 63.5;          // 2.5" between tire inside edges
// Layout: 1" + 3" + 2" + 3" + 1" = 10"
arch_inset = 25.4;          // 1" from each edge
front_fender_raise = 12.7;  // front fender raised 0.5" from ground

// --- MOUNTING TABS (front wall, integrated) ---
mtab_w      = 15;           // tab width (Y)
mtab_depth  = 15;           // how far tab extends inward (-X)
mtab_thick  = wall;         // tab thickness (Z) — matches wall
mtab_hole_r = 1.25;         // M3 self-tap hole (2.5mm dia)
mtab_offset = 26/2 + 8.5 + 5;  // Y offset from center — just outside HC-SR04 eyes (13 + 8.5r + 5mm gap)

// --- UPPER CROSS-BRACE ---
brace_w     = wall;         // brace thickness (X) — same as wall
brace_h     = 20;           // brace height (Z)
brace_z     = 145;          // above vents (vents end ~135mm), below ceiling
brace_x     = -30;          // X position — rear of center (negative = toward back)
brace_tab_w = 15;           // screw tab width (X)
brace_tab_d = 12;           // screw tab depth extending outward through panel
brace_tab_hole_r = 1.25;   // M3 self-tap

// --- CYBERTRUCK SLOPE ---
slope_len  = 101.6;   // 4" — how far back the slope starts from front edge
slope_drop = 25.4;    // 1" — how much the front roofline drops
slope_x    = panel_l/2 - slope_len;  // X where slope begins

// --- VENTILATION (Testarossa strakes) ---
vent_count   = 4;
vent_h       = 4;       // slot height (mm) — tighter
vent_start_z = 95;      // first slot ~3.7" (raised a bit more)
vent_rake    = 8;       // degrees
vent_offsets = [0, 10, 21, 34];
vent_lengths = [140, 165, 180, 165];

// --- BUILD ---
module vent_strake(z, len) {
    rake = tan(vent_rake) * len / 2;
    translate([0, 1, z])
        hull() {
            translate([-len/2, 0, rake])
                rotate([90, 0, 0])
                    cylinder(h = wall + 2, r = vent_h/2, $fn = 40);
            translate([len/2, 0, -rake])
                rotate([90, 0, 0])
                    cylinder(h = wall + 2, r = vent_h/2, $fn = 40);
        }
}

module arch_cutout() {
    cube([arch_w, wall + 2, arch_h - arch_r]);
    translate([arch_r, 0, arch_h - arch_r])
        rotate([-90, 0, 0])
            cylinder(h = wall + 2, r = arch_r, $fn = 60);
}

// Side panel with Cybertruck slope built into the profile
module side_panel() {
    difference() {
        // Panel shape — polygon profile with slope
        rotate([90, 0, 0])
            linear_extrude(height = wall)
                polygon([
                    [-panel_l/2, 0],                      // bottom-rear
                    [panel_l/2, 0],                        // bottom-front
                    [panel_l/2, panel_h - slope_drop],     // top-front (lowered)
                    [slope_x, panel_h],                    // slope start
                    [-panel_l/2, panel_h]                  // top-rear
                ]);

        // Rear wheel arch (rectangle + semicircle top)
        translate([-panel_l/2 + arch_inset, 1, 0])
            rotate([90, 0, 0])
                linear_extrude(height = wall + 2)
                    union() {
                        square([arch_w, arch_h - arch_r]);
                        translate([arch_r, arch_h - arch_r])
                            circle(r = arch_r, $fn = 60);
                    }

        // Front wheel arch (rectangle + semicircle top)
        translate([panel_l/2 - arch_inset - arch_w, 1, 0])
            rotate([90, 0, 0])
                linear_extrude(height = wall + 2)
                    union() {
                        square([arch_w, arch_h - arch_r]);
                        translate([arch_r, arch_h - arch_r])
                            circle(r = arch_r, $fn = 60);
                    }

        // Front fender raise — cut bottom 0.5" of front fender
        translate([panel_l/2 - arch_inset, -wall - 1, 0])
            cube([arch_inset + 1, wall + 2, front_fender_raise]);

        // Testarossa ventilation strakes
        for (i = [0 : vent_count - 1])
            vent_strake(vent_start_z + vent_offsets[i], vent_lengths[i]);

    }
}

// --- ASSEMBLY ---
color("#2a2a2a") {
    // Left panel
    translate([0, -panel_gap/2, 0])
        side_panel();

    // Right panel
    translate([0, panel_gap/2 + wall, 0])
        side_panel();

    // Side panel mounting tabs — between wheel arches, shelves extend inward
    // Left panel tab (shelf goes +Y inward)
    difference() {
        translate([-mtab_w/2, -panel_gap/2, 0])
            cube([mtab_w, mtab_depth + wall, mtab_thick]);
        translate([0, -panel_gap/2 + wall + mtab_depth/2, -1])
            cylinder(h = mtab_thick + 2, r = mtab_hole_r, $fn = 24);
    }
    // Right panel tab (shelf goes -Y inward)
    difference() {
        translate([-mtab_w/2, panel_gap/2 - mtab_depth, 0])
            cube([mtab_w, mtab_depth + wall, mtab_thick]);
        translate([0, panel_gap/2 - mtab_depth/2, -1])
            cylinder(h = mtab_thick + 2, r = mtab_hole_r, $fn = 24);
    }

    // Upper cross-brace — horizontal bar spanning both side panels (no external tabs)
    translate([brace_x - brace_w/2, -panel_gap/2, brace_z])
        cube([brace_w, panel_gap, brace_h]);

    // Back mounting tabs — long shelves extending inward
    btab_depth = 30;  // twice the front tab depth
    for (side = [-1, 1]) {
        difference() {
            translate([-panel_l/2, side * mtab_offset - mtab_w/2, 0])
                cube([btab_depth + wall, mtab_w, mtab_thick]);
            // Screw hole centered on shelf
            translate([-panel_l/2 + wall + btab_depth/2, side * mtab_offset, -1])
                cylinder(h = mtab_thick + 2, r = mtab_hole_r, $fn = 24);
        }
    }

    // Back wall with score lines (cut to open door)
    door_frame = 25;       // margin from edges (15% smaller door)
    door_sill  = 30;       // margin from bottom (15% smaller door)
    score_d    = 1.2;      // score line depth (half the wall)
    score_w    = 0.6;      // score line width
    door_w     = panel_gap + wall * 2 - door_frame * 2;
    door_h     = panel_h - door_sill - door_frame;
    difference() {
        translate([-panel_l/2, -panel_gap/2 - wall, 0])
            cube([wall, panel_gap + wall * 2, panel_h]);
        // Score lines — rectangle outline on outside face
        // Bottom line
        translate([-panel_l/2 - 0.01, -panel_gap/2 + door_frame - wall, door_sill])
            cube([score_d, door_w, score_w]);
        // Top line
        translate([-panel_l/2 - 0.01, -panel_gap/2 + door_frame - wall, door_sill + door_h - score_w])
            cube([score_d, door_w, score_w]);
        // Left line
        translate([-panel_l/2 - 0.01, -panel_gap/2 + door_frame - wall, door_sill])
            cube([score_d, score_w, door_h]);
        // Right line
        translate([-panel_l/2 - 0.01, -panel_gap/2 + door_frame - wall + door_w - score_w, door_sill])
            cube([score_d, score_w, door_h]);
    }

    // Back door handle — recessed finger pull (modern flush style)
    // Scoop cut into the wall so fingers can hook under and pull
    handle_w    = 40;      // width of the pull
    handle_r    = 6;       // radius of the finger scoop
    handle_z    = door_sill + 15;  // just above door bottom score line
    // Scoop: horizontal half-cylinder carved into outside face
    translate([-panel_l/2 - 0.01, 0, handle_z])
        rotate([0, -90, 0])
            rotate([0, 0, 90])
                linear_extrude(height = score_d + 0.5)
                    intersection() {
                        translate([-handle_w/2, 0])
                            square([handle_w, handle_r]);
                        scale([handle_w/2 / handle_r, 1])
                            circle(r = handle_r, $fn = 40);
                    }
    // Lip above the scoop — thin shelf to grip
    handle_lip = 2;
    translate([-panel_l/2 - handle_lip, -handle_w/2, handle_z + handle_r - 1])
        hull() {
            cube([handle_lip, handle_w, 1.5]);
            translate([handle_lip - 0.5, 0, 1.5])
                cube([0.5, handle_w, 0.5]);
        }
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

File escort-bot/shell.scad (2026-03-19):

// ============================================
// ESCORT BOT SHELL — Clean Minimal Box v4
// ============================================
// MEASURED by Romeo 2026-03-19:
//   Total width (tire-to-tire): 6" (152.4mm)
//   Tire width: 1" (25.4mm) each
//   Tire diameter: 2.5" (63.5mm)
//   Gap between front & rear tires: 2-3/8" (60.3mm)
//   Chassis length: 10" (254mm, Amazon confirmed)
// Mounting: L-brackets at 4 corners
//
// F5 = preview | F6 = render | File > Export STL
// Print: 0.2mm layer, 15% infill, no supports
// ============================================

// --- DIMENSIONS (mm) — REAL MEASUREMENTS ---
chassis_l  = 254;      // 10" front-to-back (Amazon confirmed)
chassis_w  = 100;      // frame body width (152mm tire-to-tire - 2x25.4mm tires = 101.2mm - clearance)
wheel_d    = 63.5;     // 2.5" tire diameter (measured)
wheel_w    = 25.4;     // 1" tire width (measured)
tire_gap   = 60.3;     // 2-3/8" gap between front & rear tires (measured)
wheel_r    = wheel_d / 2 + 3;  // 34.75mm — radius + 3mm clearance

// Shell height: keeping 105mm (ground-to-tallest ~165mm, plate at ~63.5mm)
shell_h    = 105;
wall       = 2.5;
tol        = 0.8;      // slide-on fit gap per side
corner_r   = 3;

// Derived outer dims
inner_l = chassis_l + tol * 2;
inner_w = chassis_w + tol * 2;
outer_l = inner_l + wall * 2;
outer_w = inner_w + wall * 2;

// Wheel arch height — how tall the arch cutout is from the bottom
// Tires are 63.5mm diameter, poke ~6mm above the support plate
wheel_arch_h = 40;

// Wheel positions — DERIVED FROM TIRE GAP MEASUREMENT
// Axle-to-axle = tire_gap + wheel_d = 60.3 + 63.5 = 123.8mm
// wx = half that distance from chassis center
wx = (tire_gap + wheel_d) / 2;  // ~61.9mm from center
wy = outer_w / 2;               // wheels at the side walls

// L-bracket mounting — 4 corners
bracket_hole_d = 5;    // M3 or M4 screw + clearance
bracket_tab_w  = 12;   // tab width
bracket_tab_d  = 12;   // tab depth (inward from wall)
bracket_tab_h  = 3;    // tab thickness
bracket_z      = 15;   // height above bottom edge
// Bracket tab inset from wheel arch (so they don't collide)
bracket_inset  = 20;   // mm inboard from wheel arch center

// Mast hole
mast_d = 35;          // 1" PVC + clearance
mast_x = 0;
mast_y = -40;         // rear-center

// HC-SR04 front face
sr04_eye_r   = 8.5;
sr04_eye_gap = 26;
sr04_z       = 52;    // mid-height of shell

// USB-C rear slot
usbc_w = 16;
usbc_h = 10;
usbc_z = 5;

// Top vents over Pi
vent_w     = 50;
vent_h     = 2.5;
vent_count = 5;
vent_gap   = 8;
vent_x     = 35;

// ============================================
// BUILD
// ============================================

module rounded_rect(l, w, h, r) {
    hull() {
        for (x = [-l/2+r, l/2-r])
            for (y = [-w/2+r, w/2-r])
                translate([x, y, 0])
                    cylinder(r=r, h=h, $fn=16);
    }
}

module shell() {
    difference() {
        union() {
            // Outer box
            rounded_rect(outer_l, outer_w, shell_h, corner_r);

            // --- L-BRACKET MOUNTING TABS (4 corners, inside) ---
            for (fb = [1, -1]) {
                for (side = [1, -1]) {
                    translate([
                        fb * (inner_l/2 - bracket_tab_w/2 - bracket_inset),
                        side * (inner_w/2 - bracket_tab_d),
                        bracket_z
                    ])
                        cube([bracket_tab_w, bracket_tab_d, bracket_tab_h]);
                }
            }
        }

        // Hollow (open bottom)
        translate([0, 0, -0.1])
            rounded_rect(inner_l, inner_w, shell_h - wall + 0.1, corner_r);

        // --- WHEEL ARCHES (4 corners) ---
        // 2.5" diameter x 1" wide tires — measured 2026-03-19
        for (side = [1, -1]) {
            for (fb = [1, -1]) {
                // Arch: wheel_r radius x (wheel_w + 6mm clearance) deep
                translate([fb * wx, side * (wy - wheel_w/2 - 3), 0])
                    hull() {
                        cylinder(r=wheel_r, h=wheel_arch_h, $fn=48);
                        translate([0, side * (wheel_w + 6), 0])
                            cylinder(r=wheel_r, h=wheel_arch_h, $fn=48);
                    }
            }
        }

        // --- L-BRACKET SCREW HOLES (through the tabs) ---
        for (fb = [1, -1]) {
            for (side = [1, -1]) {
                translate([
                    fb * (inner_l/2 - bracket_tab_w/2 - bracket_inset),
                    side * (inner_w/2 - bracket_tab_d/2),
                    bracket_z - 0.1
                ])
                    cylinder(d=bracket_hole_d, h=bracket_tab_h + 0.2, $fn=24);
            }
        }

        // --- MAST HOLE (top) ---
        translate([mast_x, mast_y, shell_h - wall - 0.1])
            cylinder(d=mast_d, h=wall + 0.2, $fn=48);

        // --- HC-SR04 EYES (front wall) ---
        for (dy = [-sr04_eye_gap/2, sr04_eye_gap/2]) {
            translate([outer_l/2, dy, sr04_z])
                rotate([0, 90, 0])
                    cylinder(r=sr04_eye_r, h=wall*2, center=true, $fn=32);
        }

        // --- USB-C SLOT (rear wall) ---
        translate([-outer_l/2 - 0.1, -usbc_w/2, usbc_z])
            cube([wall + 0.2, usbc_w, usbc_h]);

        // --- VENT SLOTS (top) ---
        for (i = [0 : vent_count - 1]) {
            translate([
                vent_x - vent_w/2,
                i * vent_gap - (vent_count - 1) * vent_gap / 2,
                shell_h - wall - 0.1
            ])
                cube([vent_w, vent_h, wall + 0.2]);
        }

        // --- REAR WIRE SLOT (bottom of back wall) ---
        translate([-outer_l/2 - 0.1, -30, 0])
            cube([wall + 0.2, 60, 12]);

        // --- SIDE WIRE SLOT (bottom of left wall) ---
        translate([-20, outer_w/2 - wall - 0.1, 0])
            cube([40, wall + 0.2, 10]);
    }
}

// ============================================
// RENDER
// ============================================

color("#2a2a2a") shell();

// Info
echo(str("=== ESCORT BOT SHELL v4 — MEASURED ==="));
echo(str("Outer: ", outer_l, " x ", outer_w, " x ", shell_h, " mm"));
echo(str("Inner: ", inner_l, " x ", inner_w, " mm"));
echo(str("Wheel: ", wheel_d, "mm dia x ", wheel_w, "mm wide (MEASURED)"));
echo(str("Wheel arch: ", wheel_r*2, "mm arc x ", wheel_arch_h, "mm tall"));
echo(str("Tire gap: ", tire_gap, "mm | Axle-to-axle: ", tire_gap + wheel_d, "mm"));
echo(str("Wheel center offset (wx): ", wx, "mm from center"));
echo(str("L-bracket holes: ", bracket_hole_d, "mm at Z=", bracket_z, "mm"));
echo(str("Wall: ", wall, "mm | Tol: ", tol, "mm/side"));

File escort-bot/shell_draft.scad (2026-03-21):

// ============================================
// ESCORT BOT — SIDE PANEL ONLY
// ============================================
// Measured by Romeo 2026-03-19:
//   Tire diameter: 2.5" (63.5mm)
//   Gap between front & rear tires: 2.5" (63.5mm)
// ============================================

// --- MEASUREMENTS ---
wheel_d    = 63.5;     // 2.5" tire diameter
tire_gap   = 69.85;    // 2-3/4" gap between front & rear tires
wheel_r    = 76.2 / 2;         // 3" wide arches (38.1mm radius)

// --- SIDE PANEL DIMS ---
panel_h    = 127;      // 5" tall (to outside edge of ceiling)
wall       = 2.5;      // wall thickness
wheel_arch_h = 40;     // arch cutout height from bottom
panel_gap  = 114.3;    // 4.5" between the two side panels

// Panel length = front arch + gap + rear arch
// Axle-to-axle = tire_gap + wheel_d = 127mm
// Panel extends a bit past each wheel center
wx = (tire_gap + wheel_d) / 2;  // 63.5mm — wheel center from midpoint
panel_l    = wx * 2 + wheel_r * 2 + 10;  // total length with some margin

// --- BUILD ---
frame_head = 28.575;   // 1-1/8" — front arch stops here (frame head height)

module side_panel() {
    difference() {
        // Flat panel
        translate([-panel_l/2, 0, 0])
            cube([panel_l, wall, panel_h]);

        // Front wheel arch
        translate([wx, wall + 0.1, 0])
            rotate([90, 0, 0])
                cylinder(r=wheel_r, h=wall + 0.2, $fn=48);

        // Rear wheel arch
        translate([-wx, wall + 0.1, 0])
            rotate([90, 0, 0])
                cylinder(r=wheel_r, h=wall + 0.2, $fn=48);

        // Trim 1" from back end (length only, full height)
        translate([-panel_l/2 - 0.1, -0.1, -0.1])
            cube([25.4, wall + 0.2, panel_h + 0.2]);

    }
}

// Left panel
color("#2a2a2a")
    translate([0, panel_gap/2, 0])
        side_panel();

// Right panel (mirrored)
color("#2a2a2a")
    translate([0, -panel_gap/2 - wall, 0])
        side_panel();

// Ceiling — shortened 1" at back to match side panels
color("#333")
    translate([-panel_l/2 + 25.4, -panel_gap/2 - wall, panel_h - wall])
        cube([panel_l - 25.4, panel_gap + wall * 2, wall]);

// Back panel — moved forward 1", bottom fine-tuned
color("#2a2a2a")
    translate([-panel_l/2 + 25.4, -panel_gap/2 - wall, wheel_r - 4.0])
        cube([wall, panel_gap + wall * 2, panel_h - (wheel_r - 4.0)]);


// Front panel wall
color("#2a2a2a")
    translate([panel_l/2 - wall, -panel_gap/2 - wall, 0])
        cube([wall, panel_gap + wall * 2, panel_h]);

echo(str("Panel length: ", panel_l, " mm"));
echo(str("Panel height: ", panel_h, " mm"));
echo(str("Panel gap: ", panel_gap, " mm (4.5\")"));
echo(str("Wheel arch radius: ", wheel_r, " mm"));
echo(str("Axle-to-axle: ", tire_gap + wheel_d, " mm"));

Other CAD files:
reference/3d-source/elktron-robots.blend
reference/3d-source/optic-staging-tray.blend

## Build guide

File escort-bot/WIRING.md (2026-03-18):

# Elktron Escort Bot — Wiring Guide

## GPIO Pin Map (BCM numbering)

```
┌─────────────────────────────────────────────────┐
│              RASPBERRY PI 5                      │
│                                                  │
│  Pin  │ BCM │ Function        │ Connects To      │
│───────┼─────┼─────────────────┼──────────────────│
│  11   │  17 │ Left Motor FWD  │ L298N IN1        │
│  18   │  24 │ Left Motor BWD  │ L298N IN2        │
│  15   │  22 │ Right Motor FWD │ L298N IN3        │
│  16   │  23 │ Right Motor BWD │ L298N IN4        │
│  37   │  26 │ Ultrasonic ECHO │ HC-SR04 ECHO     │
│  22   │  25 │ Ultrasonic TRIG │ HC-SR04 TRIG     │
│  32   │  12 │ Pan Servo PWM   │ Pan-Tilt PAN     │
│  33   │  13 │ Tilt Servo PWM  │ Pan-Tilt TILT    │
│   3   │   2 │ I2C SDA         │ LCD SDA          │
│   5   │   3 │ I2C SCL         │ LCD SCL          │
│   2   │  5V │ Sensor Power    │ HC-SR04 VCC      │
│   4   │  5V │ LCD Power       │ LCD VCC          │
│   6   │ GND │ Common Ground   │ L298N GND        │
│   9   │ GND │ Sensor Ground   │ HC-SR04 GND      │
│  14   │ GND │ LCD Ground      │ LCD GND          │
└─────────────────────────────────────────────────┘
```

## L298N Motor Driver Wiring

> **One L298N handles all 4 motors.** The L298N is a dual H-bridge (2 channels).
> The 4 TT motors wire as 2 parallel pairs — no second driver needed.
> - **Channel A** (OUT1/OUT2) → Left pair (Front-Left + Rear-Left) wired in parallel
> - **Channel B** (OUT3/OUT4) → Right pair (Front-Right + Rear-Right) wired in parallel
> Each channel's output wires reverse polarity for direction — they are NOT separate ground/hot.

```
BATTERY (7.4V)                 L298N                    MOTORS
─────────────┐          ┌──────────────┐
  (+) ───────┼──────────┤ +12V (VIN)   │         ┌── Front-Left
             │          │              ├── OUT1/2 ┤                (Channel A — LEFT)
  (-) ───────┼──────────┤ GND          │         └── Rear-Left
             │          │              │
             │          │              │         ┌── Front-Right
             │          │              ├── OUT3/4 ┤                (Channel B — RIGHT)
             │          │              │         └── Rear-Right
             │     Pi ──┤ IN1 ← GPIO17 │
             │     Pi ──┤ IN2 ← GPIO24 │
             │     Pi ──┤ IN3 ← GPIO22 │
             │     Pi ──┤ IN4 ← GPIO23 │
             │          │              │
             │     5V ──┤ +5V (logic)  │  ← REQUIRED — see ENA/ENB note below
             │          │              │
             │  Pi GND ─┤ GND          │  ← COMMON GROUND (critical!)
             │          └──────────────┘
```

### ENA / ENB Jumpers — CRITICAL

The L298N has **two enable pins** (ENA for Channel A, ENB for Channel B). Each enable pin sits between a pair of **dual header pins** on the board edge.

**To get motors spinning, you MUST jumper ENA and ENB:**

```
L298N Board Edge (top view)
┌────────────────────────────────────┐
│                                    │
│   [ENA•─•]  ← jumper these two    │
│                pins together       │
│   OUT1  OUT2   IN1  IN2           │
│                                    │
│   OUT3  OUT4   IN3  IN4           │
│                                    │
│   [ENB•─•]  ← jumper these two    │
│                pins together       │
│                                    │
│   +12V  GND  +5V                  │
└────────────────────────────────────┘
```

**How to jumper:** Use a **female-to-female dupont wire** to loop each enable pin's two header pins to each other. This connects enable HIGH, giving full speed on that channel.

**Without these jumpers, motors will NOT spin** — GPIO signals reach IN1-IN4 but the H-bridge outputs stay disabled. This is the #1 reason for "GPIO works but wheels don't move."

**+5V logic pin:** The L298N's **+5V pin** must be connected to **Pi 5V** (pin 2 or 4). When battery voltage is >7V, the onboard regulator can supply 5V — but it's more reliable to feed 5V from the Pi. **Remove the onboard regulator jumper** (the jumper near the +5V pin) if you're feeding external 5V.

## HC-SR04 Ultrasonic Sensor

```
HC-SR04          Pi 5
────────         ─────
VCC ──────────── 5V (Pin 2)
TRIG ─────────── GPIO25 (Pin 22)
ECHO ──┬── 1kΩ ── GPIO26 (Pin 37)   ← VOLTAGE DIVIDER (5V → 3.3V)
       └── 2kΩ ── GND               ← Protects Pi GPIO from 5V
GND ──────────── GND (Pin 9)
```

> **IMPORTANT:** The HC-SR04 ECHO pin outputs 5V. Pi 5 GPIO is 3.3V tolerant.
> Use the voltage divider (1kΩ + 2kΩ resistors) — 1:2 ratio gives ~3.33V output.
> Without the divider you risk frying the GPIO pin.
> Alternative: use HC-SR04P (3.3V version) and skip the divider.

## I2C LCD Screen

```
LCD Module       Pi 5
──────────       ─────
GND ──────────── GND (Pin 14)
VCC ──────────── 5V  (Pin 4)
SDA ──────────── GPIO2 / SDA1 (Pin 3)
SCL ──────────── GPIO3 / SCL1 (Pin 5)
```

> The LCD uses the **I2C bus** (dedicated pins, no conflict with motor/sensor GPIOs).
> Most I2C LCD modules have a default address of `0x27` or `0x3F`.
> Scan for the address after wiring:
> ```bash
> sudo i2cdetect -y 1
> ```
> Enable I2C on the Pi if not already:
> ```bash
> sudo raspi-config nonint do_i2c 0
> ```

## Pan/Tilt Servos

```
Pan Servo        Pi 5
─────────        ─────
Signal ────────── GPIO12 (Pin 32)
VCC ──────────── 5V (Pi 5V rail or external)
GND ──────────── GND

Tilt Servo       Pi 5
──────────       ─────
Signal ────────── GPIO13 (Pin 33)
VCC ──────────── 5V
GND ──────────── GND
```

> MG90S servos draw ~150mA each. Two servos = ~300mA from the 5V rail.
> If the Pi brownouts under load, power servos from the battery pack through a 5V BEC instead.

## Camera

Arducam IMX708 120° wide-angle connects via **CSI ribbon cable** to the CAM port on the Pi 5.
Powered internally by the Pi — no external wiring needed.

## Power (Fully Portable — Two Separate Sources)

```
USB-C Power Bank (5V/3A+) ──── Pi 5 USB-C port
  └── right-angle USB-C adapter → inline power switch → Pi
  └── Backup power bank ready for hot-swap

18650 x2 in series (7.4V) ──── L298N +12V (VIN)
  └── Powers motors through L298N
  └── 2 spare 18650s charged and ready

Pi 5V rail ──── Sensors + Servos + LCD
  └── HC-SR04 VCC
  └── Pan/tilt servos (~300mA total)
  └── LCD VCC
  └── Camera (CSI, powered internally by Pi)

CRITICAL: Common GND between Pi and L298N!
```

Two separate power sources:
1. Pi runs off USB-C power bank (5V/3A minimum — Pi 5 brownouts on weak banks)
2. Motors run off 18650 battery pack through L298N

Do NOT power the Pi from the L298N's 5V regulator — it can't supply enough current for Pi 5 under CV load (~3A).

## Quick Test Commands

```bash
# Test camera
libcamera-hello --timeout 5000

# Test ultrasonic (Python)
python3 -c "from gpiozero import DistanceSensor; s=DistanceSensor(echo=26,trigger=25); print(f'{s.distance*100:.1f}cm')"

# Test motors (Python) — wheels will spin!
python3 -c "from gpiozero import Robot; r=Robot(left=(17,24),right=(22,23)); r.forward(0.3); import time; time.sleep(1); r.stop()"

# Scan I2C bus for LCD address
sudo i2cdetect -y 1

# Test LCD (after installing RPLCD)
python3 -c "from RPLCD.i2c import CharLCD; lcd=CharLCD('PCF8574',0x27); lcd.write_string('Elktron Bot')"

# Test pan/tilt servos
python3 pan_tilt.py --simulate
```

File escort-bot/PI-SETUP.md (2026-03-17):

# Escort Bot — Raspberry Pi 5 Setup Guide

> **Target hardware:** Raspberry Pi 5 (4GB or 8GB)
> **Required OS:** Raspberry Pi OS Bookworm 64-bit (Lite recommended)
> **Last updated:** 2026-03-09

---

## Why This OS?

| Requirement | Why Bookworm 64-bit Lite |
|---|---|
| **Pi 5 support** | Bookworm is the **only** official OS for Pi 5. Bullseye does NOT support Pi 5. |
| **64-bit** | Required for OpenCV DNN performance. 32-bit halves inference speed on Pi 5's Cortex-A76 cores. |
| **Lite (no desktop)** | Robot runs headless. No GPU wasted on desktop compositor. All resources go to CV + motor control. Saves ~500MB RAM. |
| **picamera2** | Pre-installed on Bookworm. Uses libcamera stack (not legacy raspistill). |
| **gpiozero 2.0+** | Bookworm ships with lgpio backend (not RPi.GPIO), which is the only GPIO lib that works on Pi 5. |
| **Python 3.11+** | Bookworm ships Python 3.11. OpenCV wheels are built for 3.11+. |

**Do NOT use:**
- Bullseye (no Pi 5 support)
- Ubuntu (GPIO support is worse, picamera2 setup is painful)
- 32-bit (halves inference performance)
- Desktop version (wastes RAM/GPU on a headless robot)

---

## What You Need

- [ ] Raspberry Pi 5 (owned)
- [ ] MicroSD card — 32GB+ Class 10 / A2 (Samsung EVO Select or SanDisk Extreme recommended)
- [ ] SD card reader (USB or built-in)
- [ ] Your laptop/Mac
- [ ] WiFi network name + password (for headless SSH)

---

## Step 1: Download Raspberry Pi Imager

**macOS direct download:**
https://downloads.raspberrypi.com/imager/imager_latest.dmg

Or install via Homebrew:
```bash
brew install --cask raspberry-pi-imager
```

**Official page:** https://www.raspberrypi.com/software/

---

## Step 2: Flash the SD Card

1. Insert MicroSD card into your Mac
2. Open **Raspberry Pi Imager**
3. Click **CHOOSE DEVICE** → select **Raspberry Pi 5**
4. Click **CHOOSE OS** → select:
   ```
   Raspberry Pi OS (other)
     → Raspberry Pi OS Lite (64-bit)
         Debian Bookworm, no desktop
   ```
5. Click **CHOOSE STORAGE** → select your MicroSD card
6. Click **NEXT**

### IMPORTANT: Configure Settings (DO THIS!)

When prompted "Would you like to apply OS customisation settings?", click **EDIT SETTINGS**:

**General tab:**
- [x] Set hostname: `escort-bot`
- [x] Set username and password:
  - Username: `pi`
  - Password: (pick something — you'll SSH with this)
- [x] Configure wireless LAN:
  - SSID: (your WiFi network)
  - Password: (your WiFi password)
  - Country: US
- [x] Set locale:
  - Timezone: America/Chicago
  - Keyboard: us

**Services tab:**
- [x] Enable SSH → Use password authentication

Click **SAVE** → click **YES** to apply → click **YES** to confirm write.

Wait for write + verification to complete (~5-10 min).

---

## Step 3: First Boot

1. Eject SD card from Mac
2. Insert into Pi 5
3. Connect power (USB-C, 5V/3A minimum)
4. Wait ~60-90 seconds for first boot
5. Find Pi on your network:

```bash
# From your Mac terminal:
ping escort-bot.local

# If that doesn't resolve, scan the network:
arp -a | grep -i "raspberry\|dc:a6\|b8:27\|d8:3a\|2c:cf"
# Or use: brew install nmap && nmap -sn 192.168.1.0/24
```

6. SSH in:
```bash
ssh pi@escort-bot.local
# Enter your password when prompted
```

---

## Step 4: Run the Install Script

Once SSH'd into the Pi:

```bash
# Clone or copy the escort-bot code to Pi
# Option A: scp from your Mac
# (run this on your Mac, not the Pi)
scp -r ~/hackathon/escort-bot/ pi@escort-bot.local:~/escort-bot/

# Option B: git clone (if repo is pushed)
# git clone <repo-url> ~/escort-bot

# Then on the Pi:
cd ~/escort-bot
chmod +x install.sh
./install.sh
```

This installs: picamera2, OpenCV, gpiozero, lgpio, and downloads the MobileNet SSD model.

---

## Step 5: Verify Everything Works

```bash
# Test camera (should show 5 seconds of video output info)
libcamera-hello --timeout 5000

# Test GPIO (should print pin info without errors)
python3 -c "from gpiozero import Device; print('GPIO OK:', Device.pin_factory)"

# Test OpenCV DNN (should print model loaded)
python3 -c "
import cv2
net = cv2.dnn.readNetFromTensorflow('models/ssd_mobilenet_v2.pb', 'models/ssd_mobilenet_v2.pbtxt')
print('OpenCV DNN OK. Backend:', cv2.dnn.DNN_BACKEND_OPENCV)
"

# If all three pass, run the bot:
python3 main.py
```

---

## Troubleshooting

| Issue | Fix |
|---|-----|
| `ssh: connect to host escort-bot.local port 22: Connection refused` | Pi hasn't finished booting. Wait 90s. Or WiFi creds were wrong — reflash with correct SSID/password. |
| `ModuleNotFoundError: No module named 'lgpio'` | Run `sudo apt install python3-lgpio` — Pi 5 needs lgpio, not RPi.GPIO |
| `libcamera-hello` shows no camera | Check CSI ribbon cable is seated firmly. Use the Pi 5 CSI port (between HDMI ports). |
| `python3-opencv` not found | Run `sudo apt install python3-opencv` (preferred over pip on Pi) |
| Pi throttles / gets hot | Attach heatsink or active cooler. Pi 5 throttles at 85°C under CV workload. |
| GPIO permission denied | Add user to gpio group: `sudo usermod -aG gpio pi && reboot` |

---

## Performance Tips for Demo Day

- **Overclock (optional):** Add `arm_freq=2800` to `/boot/firmware/config.txt` (up from 2400MHz default). Needs active cooling.
- **Disable Bluetooth** (saves CPU): `sudo systemctl disable bluetooth`
- **Disable swap** (SD card longevity): `sudo dphys-swapfile swapoff && sudo systemctl disable dphys-swapfile`
- **Pin CPU governor:** `echo performance | sudo tee /sys/devices/system/cpu/cpu*/cpufreq/scaling_governor`

---

## Claude Code (AI-Assisted Dev on the Pi)

Claude Code CLI is installed on the Pi. This gives you an AI coding assistant directly on the robot hardware.

```bash
# SSH into Pi, then:
cd ~/escort-bot
claude
```

**What this unlocks:**
- Edit and debug `main.py`, `pan_tilt.py`, `test_camera.py` without leaving the Pi
- Ask Claude to read sensor output, inspect GPIO pins, and fix code in one loop
- Iterate on motor calibration, detection thresholds, and PID tuning with AI assistance
- On demo day: rapid on-site fixes without needing a laptop with the codebase

**Tip:** Run `claude` in the `~/escort-bot` directory so it picks up the project CLAUDE.md for full context.

---

## Quick Reference

| Item | Value |
|---|---|
| OS | Raspberry Pi OS Lite (64-bit) — Bookworm |
| Hostname | `escort-bot` |
| Username | `pi` |
| SSH | `ssh pi@escort-bot.local` |
| Python | 3.11+ (system) |
| GPIO lib | lgpio (via gpiozero 2.0+) |
| Camera lib | picamera2 + libcamera |
| ML runtime | OpenCV DNN (MobileNet SSD v2) |
| AI dev tool | Claude Code CLI (installed) |
| Imager download | https://downloads.raspberrypi.com/imager/imager_latest.dmg |
| OS downloads | https://www.raspberrypi.com/software/operating-systems/ |

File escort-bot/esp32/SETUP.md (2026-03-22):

# ESP-NOW RC Controller Setup

## What You Have
- 2x ESP32-CAM modules
- 1x ESP32-CAM-MB programmer (clip-on cradle)
- 5x tactile push buttons + wires (for controller)

## Flashing Steps

### 1. Install Arduino IDE + ESP32 Board Support
```bash
# Arduino IDE → File → Preferences → Additional Board URLs:
# https://raw.githubusercontent.com/espressif/arduino-esp32/gh-pages/package_esp32_index.json
# Then: Tools → Board Manager → search "esp32" → install
```

### 2. Get Receiver MAC Address
1. Clip **receiver** ESP32-CAM into programmer cradle
2. Arduino IDE → Tools → Board: **AI Thinker ESP32-CAM**
3. Open `get_mac/get_mac.ino` → Upload
4. Open Serial Monitor (115200 baud)
5. Copy MAC address (e.g., `24:6F:28:AB:CD:EF`)

### 3. Flash Controller
1. Open `controller/controller.ino`
2. Replace `RECEIVER_MAC` with the MAC from step 2:
   ```c
   uint8_t RECEIVER_MAC[] = {0x24, 0x6F, 0x28, 0xAB, 0xCD, 0xEF};
   ```
3. Clip **controller** ESP32-CAM into programmer → Upload

### 4. Flash Receiver
1. Clip **receiver** ESP32-CAM back into programmer
2. Open `receiver/receiver.ino` → Upload
3. Remove from programmer

### 5. Wire Controller Buttons
```
GPIO 13 ──┤ FWD button  ├── GND
GPIO 15 ──┤ BACK button ├── GND
GPIO 14 ──┤ LEFT button ├── GND
GPIO 2  ──┤ RIGHT button├── GND
GPIO 4  ──┤ TURBO button├── GND
```
Power controller from USB power bank (micro USB into programmer cradle).

### 6. Wire Receiver to Pi 5
```
ESP32-CAM          Pi 5
─────────          ────
GPIO 1 (TX)  →  GPIO 15 (RXD)
GND          →  GND
```
Power receiver from Pi's 3.3V or 5V pin.

### 7. Enable UART on Pi 5
```bash
sudo raspi-config
# Interface Options → Serial Port
# Login shell over serial: NO
# Serial port hardware enabled: YES
sudo reboot
```

### 8. Run Motor Control
```bash
cd ~/hackathon/escort-bot/esp32
python3 rc_drive.py           # listen for commands
python3 rc_drive.py --test    # test motors without ESP32
```

## Troubleshooting
- **No serial data:** Check TX→RX wiring (crossed). Verify UART enabled.
- **Motors don't move:** Check L298N 12V power (batteries), verify GND shared between L298N and Pi.
- **ESP-NOW timeout:** Both ESP32-CAMs must be on same WiFi channel (default 0 = auto).
- **Flash fails:** Hold IO0 button while pressing RST on programmer, then release IO0.

## Emergency Stop
Press **Forward + Backward** simultaneously on controller = E-STOP.

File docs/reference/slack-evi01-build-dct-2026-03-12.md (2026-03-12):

# EVI01-BUILD-DCT Slack — March 12, 2026

Snapshot of the #evi01-build-dct channel. Shows typical DCT daily work at EVI01.

---

## Rodrigo Alba — 11:51 AM
- Posted `coreweave_critical_load_2026` image (critical load planning)

## Rodrigo Alba — 12:13 PM
- Tagged @Raphael Rojo @James Logan @Rodney Ballard
- **New Corning cables** came in — slightly different from existing ones
  - Different part number, loose bundles, red cable running through them
  - **New:** `G-BND08-Z1Z1Q-PN000-XXXM`
  - **Old:** `G-BND08-Z1Z1T-PN000-XXXM`
- Attached 4 photos (10168.jpg–10171.jpg)

## Rodrigo Alba — 12:21 PM
- **2nd shift task:** Continue installing switches, power cables, and optics in all B200 newly delivered in DH2

## Roy Alfaro — 2:22 PM
- 1 year anniversary at CW
- Posted photo (1000034733.jpg)

## Brian McClure — 6:13 PM
- **Progress:** 2 full pods staged and complete, ~2/3 of the next one done
- Will pick up in the AM
- Attached 2 photos (IMG_5374, IMG_5375)

---

## Why This Matters for Elktron
- Shows the exact work DCTs do daily: switch installs, optic seating, cable runs, pod staging
- The SO-101 arm targets **optic seating** — one of the tasks mentioned here
- The escort bot targets **vendor walkthroughs** during builds like this
- Good pitch material: "This is what our team does every day. Elktron automates the repetitive parts."

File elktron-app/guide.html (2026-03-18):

Visual Guide

# How to Read the Elktron Dashboard

A plain-English walkthrough of every panel, badge, number, and button. No jargon. If you can read a car dashboard, you can read this.

0

The Top Bar

Connection status + clock

Elktron

| DEMO MODE

14:35:22 Connected

+

#### Green dot = alive

The green circle next to "Elktron" means the dashboard is receiving data. If it turns red, something disconnected.

M

#### Mode badge

DEMO MODE = running simulated data (no real robots connected). MOCK DATA = server running but no hardware. LIVE HARDWARE = real robots connected.

C

#### Connection badge (top right)

Connected = getting live data. Demo = simulated. Disconnected = nothing coming in.

1

SO-ARM101 Panel

The robot arm that seats optics into switches

SO-ARM101

Active

Transiting

Carrying optic to switch

Base

-24.3

Rotation angle in degrees

Shoulder

-1.8

Up/down tilt of upper arm

Torque

12.4

How hard the motors are working

Accuracy

+/-0.8mm

How precise the placement is

P

#### Phase (big text at top)

What the arm is doing right now. Cycles through: Idle (waiting) > Reaching (moving to tray) > Gripping (picking up optic) > Transiting (carrying it) > Inserting (seating into port) > Releasing > Retracting (going home). One full cycle takes ~12 seconds.

J

#### Joint angles (6 boxes)

Each box is one motor in the arm. The number = rotation angle in degrees. They flash blue when they change. You don't need to understand the exact numbers — just know that movement = the arm is working.

G

#### Gripper indicator

Shows whether the claw is Open, Closed, or Holding Optic. When it says "Holding Optic" the arm has grabbed a transceiver and is carrying it.

Badge colors:

Ready = idle, waiting

Active = moving

Inserting = critical step

Bottom stats: Torque = motor effort (higher = heavier load). Temp = motor temperature in Celsius (normal: 36-42). Accuracy = placement precision in millimeters. Cycles = total optics seated this session.

2

Escort Bot Panel

The robot that follows vendors and scans racks

Escort Bot

Scanning

Scanning

Scanning rack nodes top to bottom

TechCo Field Eng.

INC-40821

AUTHORIZED: CAB-B3 / RU-24 ONLY

Rack Scan67%

P

#### Phase (big text)

What the bot is doing: Idle (charging) > Dispatched (heading to vendor) > Escorting (walking with them) > Arrived (at rack) > Scanning (checking nodes) > Monitoring (watching for unauthorized touches) > Verified (all clear) > Returning (going back). Full cycle: ~30 seconds in demo.

V

#### Vendor card

Shows who the bot is escorting: vendor name, ticket number, and which rack + rack unit they're authorized to touch. Appears when a vendor is assigned, disappears when the escort is done.

S

#### Scan progress bar

Green bar filling up = the bot is scanning each node in the rack from top to bottom. 100% = scan complete. The bar glows while actively scanning.

!

#### Alert banner (amber/green)

Pops up when the bot detects someone touching an unauthorized rack unit. Amber = "checking..." (contact detected, verifying). Green = "cleared" (false alarm, no state change). A real alert that stays amber = problem.

Bottom stats: Location = where the bot is (aisle name or rack ID). Battery = charge level (starts at 95%, drains slowly). Nodes = how many rack units have been scanned so far.

3

Camera Feeds

Live video from both robots

Camera Feeds

2 Sources

Wrist Cam NO SIGNAL

Escort Cam NO SIGNAL

W

#### Wrist Cam (left)

Mounted on the SO-101 arm's wrist. Shows what the arm sees when picking up and placing optics. Used for visual inspection during insertion.

E

#### Escort Cam (right)

Mounted on the escort bot. Shows the person it's following and the rack it's scanning. This is how the bot detects people and reads rack state.

In demo mode: Cameras show "No Signal" with a static animation. When real hardware is connected, these show live video with bounding boxes around detected objects. The red "LIVE" dot in the corner pulses when the feed is active.

4

Rack Scan Log

History of every vendor visit and rack scan

Rack Scan Log

3 Scans

TimeVendorResultFlags

11:35 TechCo Field Eng. Clean 1

Yesterday DataLink Corp. Flagged 2

C

#### Clean = all good

The vendor only touched what they were authorized to touch. Rack state before and after matches. No concerns.

F

#### Flagged = something changed

The bot detected unauthorized contact or unexpected state changes. The "Flags" column shows exactly what happened (e.g., "RU-29 unauthorized contact" or "RU-30 optic swapped").

D

#### Other columns

Rack = which cabinet. Auth RU = which rack unit the vendor was allowed to touch. Nodes = how many units were scanned. Duration = how long the whole escort took.

5

Training Console

How the arm learns new tasks

Training Console

Recording

Recording

Recording teleoperation episodes

Episodes

23

Demonstrations recorded so far

Loss

0.1280

Lower = model is learning better

GPU

Shows GPU when training runs

Cost

$2.76

Cloud compute cost so far

1

#### Start Recording

A human demonstrates the task (e.g., seat an optic) while the arm mirrors and records the movement. Each demo = 1 episode. We need ~50 episodes for the arm to learn.

2

#### Upload Data

Sends all recorded episodes to the cloud for training. Progress bar shows upload status.

3

#### Train Model

Starts training on a cloud GPU (A100). The model watches all 50 demos and learns the pattern. Takes 2-4 hours, runs unattended. The "Loss" number goes down as it gets better.

4

#### Deploy

Downloads the trained model and loads it onto the arm. After this, the arm can do the task autonomously — no human needed.

Button behavior: During recording, only the Record button is active (pulsing green). During training, only the Train button is active. Other buttons are dimmed out. This prevents you from accidentally starting two things at once.

?

Dashboard Modes

What the different connection states mean

D

#### Demo Mode (what you see now)

No server, no robots. The dashboard generates fake data so you can see how everything looks and moves. Opens from a file — just double-click index.html. All panels animate with realistic simulated cycles.

M

#### Mock Mode (server, no hardware)

The Python server is running (uvicorn server:app) but no robots are plugged in. Server generates the same simulated data but over a real WebSocket. Good for testing the full stack.

L

#### Live Hardware Mode

Real robots connected via USB. The arm sends actual joint angles, the escort bot sends real camera frames and sensor readings. This is the goal for demo day.

How to tell which mode you're in: Look at the top bar. "DEMO MODE" (blue) = standalone. "MOCK DATA" (gray) = server without hardware. "LIVE HARDWARE" (green) = the real thing.

Open Dashboard

Elktron · CoreWeave Hackathon 2026

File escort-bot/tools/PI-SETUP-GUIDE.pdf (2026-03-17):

Elktron Escort Bot — Pi 5 Setup Guide | Page 1

ELKTRON

# Escort Bot

## Raspberry Pi 5 Setup Guide

Everything you need to go from a blank Raspberry Pi to a working robot — no tech experience required. Every command is explained in plain English.

## What You Need

[ ] Raspberry Pi 5

The robot's brain — a small green computer board
[ ] MicroSD Card (32GB+)

Tiny memory card — stores the operating system and robot code
[ ] SD Card Reader

Plugs the microSD into your laptop so you can install the OS
[ ] USB-C Power Supply or Power Bank

Powers the Pi — like a phone charger (5V, 3A minimum)
[ ] Laptop or Mac

Used to set up the SD card and connect to the Pi remotely
[ ] WiFi Network + Password

The Pi connects to WiFi so you can control it from your laptop
[ ] HDMI Monitor + Micro-HDMI Cable (optional)

Only if WiFi setup fails — lets you see the Pi's screen directly

TIP: Get everything laid out on a table before you start. The whole setup takes about 30 minutes.

## STEP 01 Flash the SD Card

Think of the SD card like a USB drive for the Pi. Right now it's blank — we need to put an operating system on it (like installing Windows on a new computer, but way simpler).

1a. Download Raspberry Pi Imager
This is the official tool from Raspberry Pi that writes the operating system onto your SD card. It's free and works on Mac, Windows, and Linux.

On your laptop (not the Pi), go to:

https://www.raspberrypi.com/software/
Or on Mac, open Terminal and type:

brew install --cask raspberry-pi-imager

What is Terminal? It's an app on your Mac that lets you type commands. Find it in Applications > Utilities > Terminal, or press Cmd+Space and type "Terminal".

1b. Write the OS to the SD Card
Plug your MicroSD card into your laptop (use the SD card reader if needed). Then:

1. Open Raspberry Pi Imager — Double-click the app you just downloaded 2. Click CHOOSE DEVICE — Select "Raspberry Pi 5" from the list 3. Click CHOOSE OS — Go to: Raspberry Pi OS (other) > Raspberry Pi OS Lite (64-bit) 4. Click CHOOSE STORAGE — Select your MicroSD card (be careful not to pick your hard

drive!)
5. Click NEXT — It will ask about settings — this is the important part...

IMPORTANT — DO NOT SKIP THIS! When it asks "Would you like to apply OS customisation settings?", click EDIT SETTINGS. This is where you set up WiFi and remote access.

1c. Configure Settings (EDIT SETTINGS screen)
These settings let you connect to the Pi over WiFi without plugging in a keyboard or monitor.
Setting | What to Enter | Why
Hostname | escort-bot | The name of your Pi on the network

Username | pi | Your login name (keep it simple)
Password | (pick something) | You'll type this to log in remotely
WiFi SSID | (your WiFi name) | Exact name — capitalization matters!
WiFi Password | (your WiFi password) | Has to be exact
Country | US | Required for WiFi to work
Timezone | America/Chicago | Or your local timezone
Enable SSH | Check the box! | This lets you control the Pi from your laptop

Click SAVE, then YES twice. Wait for it to finish writing (~5-10 min).

## STEP 02 First Boot

The SD card now has the operating system on it. Time to put it in the Pi, plug in power, and watch it come alive. You won't need a keyboard or monitor — everything is done from your laptop.

### 1. Eject the SD card from your laptop (safely remove it first)

2. Slide the MicroSD card into the Pi 5 — the slot is on the bottom of the board, label facing up

### 3. Plug in the USB-C power cable (Pi side) and connect to your power bank or wall adapter 4. Wait 60-90 seconds — the Pi is booting up and connecting to your WiFi

5. The red LED on the Pi should be solid (power) and the green LED should blink (activity)

What if nothing happens? Check that the USB-C cable is plugged in firmly. The red LED should light up immediately. If it doesn't, try a different cable or power source. Pi 5 needs at least 5V / 3A — some cheap cables can't deliver enough power.

2b. Connect to the Pi from Your Laptop
Open Terminal on your Mac (Cmd+Space, type "Terminal", hit Enter). Then type:

ssh pi@escort-bot.local
It will ask for your password — type the one you set in Step 1c. You won't see the characters as you type — that's normal! Just type it and press Enter.

What is SSH? It stands for "Secure Shell." It lets you control the Pi's command line from your laptop, over WiFi. It's like remote desktop, but text-only.

If escort-bot.local doesn't work:
Find the Pi's IP address by running this on your Mac:
arp -a | grep -i "raspberry\|dc:a6\|b8:27\|d8:3a\|2c:cf"
Then connect using the IP address instead:

ssh pi@192.168.1.XXX
(Replace XXX with the actual number you found)

## STEP 03 Set Up WiFi (If Not Already Connected)

If you set WiFi in Step 1c, you can skip this. But if the Pi didn't connect to WiFi (or you need to change networks), here's how to do it from the command line.

If you're connected via SSH, WiFi is already working — skip to Step 4. If you're on a keyboard+monitor plugged directly into the Pi, do this:

Option A — The easy way (graphical menu):

sudo raspi-config
Use arrow keys to go to: System Options > S1 Wireless LAN Type your WiFi name, press Enter, type password, press Enter. Select Finish and reboot.

Option B — Direct command (if raspi-config gives an error):

sudo nmcli dev wifi list
This shows all WiFi networks the Pi can see. Find yours in the list, then:

sudo nmcli dev wifi connect "YOUR_WIFI_NAME" password "YOUR_PASSWORD"
Replace YOUR_WIFI_NAME and YOUR_PASSWORD with your actual WiFi credentials. Keep the quotes.

Verify WiFi is working:

ping -c 3 google.com
If you see replies with times (like "time=12.3 ms"), WiFi is working. Press Ctrl+C to stop. If you see "Network is unreachable", double-check your WiFi name and password.

WiFi still not working? Try: sudo rfkill unblock wifi then retry the nmcli command. If the WiFi chip isn't detected at all, make sure you're using Raspberry Pi OS (not Ubuntu) and the Pi 5 board isn't defective.

## STEP 04 Update the System

Just like updating your phone, the Pi needs the latest software patches before we install anything. This is always the first thing you do on a new Pi.

Run this command (copy the whole line and press Enter):

sudo apt-get update && sudo apt-get upgrade -y

What this does:

Part | What It Means
sudo | Run as administrator (like "Run as Admin" on Windows)
apt-get update | Downloads the latest list of available software
&& | "If that worked, then also do this next thing"
apt-get upgrade -y | Installs all available updates. -y means "yes to everything"

This takes 5-10 minutes. You'll see lots of text scrolling — that's normal. Don't touch anything until you see the command prompt again (the line ending with $).

## STEP 05 Install System Packages

These are the core apps the robot needs — the camera driver, the pin controller that talks to motors and sensors, and some helper tools for downloading files.

sudo apt-get install -y python3-picamera2 python3-libcamera python3-lgpio python3-pip unzip wget

Package | Plain English
python3-picamera2 | Lets the robot's code control the camera
python3-libcamera | Low-level camera driver (picamera2 needs this)
python3-lgpio | Controls the Pi's GPIO pins (motors, sensors, servos)
python3-pip | Tool for installing Python packages (like an app store for code)
unzip | Extracts .zip files (we need this for the AI model)
wget | Downloads files from the internet via command line

## STEP 06 Install Python Packages

Python is the programming language the robot uses. These packages are like apps — each one gives the robot a new ability (see with AI, control motors, take photos, etc).

Run each line one at a time. Wait for each to finish before typing the next one. You'll see "Successfully installed..." when each is done.

pip install --break-system-packages picamera2>=0.3.12

Camera interface — lets the code take photos and video

pip install --break-system-packages tflite-runtime>=2.14.0

AI engine — this is what lets the robot recognize people

pip install --break-system-packages gpiozero>=2.0

Motor/sensor controller — simple commands to drive wheels and read distances

pip install --break-system-packages lgpio>=0.2.2.0

Pi 5 pin driver — required for gpiozero to work on the Pi 5

pip install --break-system-packages numpy>=1.24.0

Math library — the AI uses this to process camera images

pip install --break-system-packages Pillow

Image library — saves photos from the camera as files

What is --break-system-packages? The Pi's new OS (Bookworm) is extra cautious about installing Python packages. This flag says "I know what I'm doing, install it anyway." It's safe for our use.

## STEP 07 Download the AI Model

The robot needs a pre-trained AI brain to recognize people. We're downloading a model from Google that already knows what a person looks like — no training needed.

Run each command one at a time:

mkdir -p ~/escort-bot/models

Creates a folder to store the AI model. The -p flag means "don't complain if it already exists."

wget -q "https://storage.googleapis.com/download.tensorflow.org/models/tflite/coco_ssd_mobilenet_v1_1.0_quant_2018_06_29.zip" -O /tmp/ssd_model.zip

Downloads the AI model from Google (4.3 MB). wget is like clicking a download link, but in the terminal.

unzip -o /tmp/ssd_model.zip -d ~/escort-bot/models/

Unzips the downloaded file into the models folder. Like double-clicking a .zip on your desktop.

mv ~/escort-bot/models/detect.tflite ~/escort-bot/models/ssd_mobilenet_v2.tflite

Renames the file so the robot's code can find it. The code looks for "ssd_mobilenet_v2.tflite" specifically.

## STEP 08 Verify Everything Works

Before we wire up motors and sensors, let's make sure the camera, GPIO pins, and AI model are all working. Think of this as a pre-flight checklist.

8a. Check the camera:

libcamera-hello --list-cameras
You should see imx708 in the output (that's the Arducam wide-angle camera). If nothing shows up, check that the ribbon cable is firmly seated in the CSI port.

8b. Check GPIO pins:

python3 -c "from gpiozero import Device; print('GPIO OK:', Device.pin_factory)"
Should print "GPIO OK: lgpio" or similar. If you get an error about lgpio, run sudo apt install
python3-lgpio and try again.

8c. Check the AI model:

python3 -c "import tflite_runtime.interpreter as tflite; i=tflite.Interpreter(model_path='models/ssd_mobilenet_v2.tflite'); i.allocate_tensors(); print('TFLite OK')"
Should print "TFLite OK". If you get a file-not-found error, re-run Step 7.

If all three checks pass, the Pi is fully set up! Next: wire up motors, sensors, and camera, then run python3 main.py to start the robot.

# Troubleshooting

Common problems and how to fix them — in plain English.

Can't connect via SSH
Symptom: ssh says "Connection refused" or hangs
The Pi hasn't finished booting, or WiFi credentials were wrong. Wait 90 seconds and try again. If still nothing, plug in a monitor + keyboard and check WiFi settings with sudo raspi-config.
WiFi won't connect
Symptom: No networks found, or connection fails
Run: sudo rfkill unblock wifi then: sudo nmcli dev wifi connect "NAME" password "PASS". If no networks show, the WiFi chip may need a moment — wait 10 seconds and try: sudo nmcli dev wifi list
Camera not detected
Symptom: libcamera-hello shows nothing
The ribbon cable isn't seated properly. Pull the black tab on the CSI connector UP, slide the cable in (blue side facing the USB ports), then push the tab DOWN to lock it. Make sure it's the CAM port, not DISP.
"No module named lgpio"
Symptom: GPIO commands fail
Run: sudo apt install python3-lgpio. Pi 5 uses lgpio, not the old RPi.GPIO library.
"externally-managed-environment"
Symptom: pip install fails with a long error
Add --break-system-packages to your pip command. This is normal on Bookworm.
Pi is slow or hot
Symptom: Throttling under load
Attach the active cooler (official heatsink+fan). Pi 5 throttles at 85C. For demo day: echo performance | sudo
tee /sys/devices/system/cpu/cpu*/cpufreq/scaling_governor
Pi won't boot at all
Symptom: No lights, no activity
Try a different USB-C cable and power source. Pi 5 needs 5V/3A minimum. Some cables are charge-only (no data) — use a known-good cable.

# GPIO Pin Reference

Which Pi pins connect to which robot parts. You'll need this for wiring.

Pi Pin # | GPIO # | What It Does | Connects To
11 | 17 | Left Motor Forward | L298N IN1
13 | 27 | Left Motor Backward | L298N IN2
15 | 22 | Right Motor Forward | L298N IN3
16 | 23 | Right Motor Backward | L298N IN4
18 | 24 | Ultrasonic Echo | HC-SR04 ECHO (through voltage divider!)
22 | 25 | Ultrasonic Trigger | HC-SR04 TRIG
32 | 12 | Pan Servo (left/right) | Pan-tilt platform
33 | 13 | Tilt Servo (up/down) | Pan-tilt platform
2 | 5V | Sensor Power | HC-SR04 VCC
6 | GND | Common Ground | Everything shares this

CRITICAL: The HC-SR04 Echo pin outputs 5V, but Pi 5 GPIO only handles 3.3V. You MUST use a voltage divider (1k + 2k ohm resistors) on the Echo wire, or use the 3.3V-safe HC-SR04P version. Skipping this can permanently damage your Pi.

# Quick Command Reference

Copy-paste cheat sheet — all the commands in one place.

What | Command
Update system | sudo apt-get update && sudo apt-get upgrade -y
Install system packages | sudo apt-get install -y python3-picamera2 python3-libcamera python3-lgpio python3-pip unzip wget
Install picamera2 | pip install --break-system-packages picamera2>=0.3.12
Install TFLite | pip install --break-system-packages tflite-runtime>=2.14.0
Install gpiozero | pip install --break-system-packages gpiozero>=2.0
Install lgpio | pip install --break-system-packages lgpio>=0.2.2.0
Install numpy | pip install --break-system-packages numpy>=1.24.0
Install Pillow | pip install --break-system-packages Pillow
Create models dir | mkdir -p ~/escort-bot/models

Download AI model | wget -q "https://storage.googleapis.com/download.tensorflow.org/models/tflite/coco_ssd_mobilenet_v1_1.0_quant_2018_06_29.zip" -O /tmp/ssd_model.zip
Unzip model | unzip -o /tmp/ssd_model.zip -d ~/escort-bot/models/
Rename model | mv ~/escort-bot/models/detect.tflite ~/escort-bot/models/ssd_mobilenet_v2.tflite
Check camera | libcamera-hello --list-cameras
Test detection | python3 test_camera.py
Start robot | python3 main.py

### You did it. The Pi is set up, the AI model is loaded, and the robot is ready to be wired. Next step: follow the Wiring Guide to connect motors, sensors, and

camera.

Elktron / Escort Bot / CoreWeave Hackathon 2026

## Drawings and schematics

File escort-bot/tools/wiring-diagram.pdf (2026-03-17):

# ESCORT BOT — WIRING DIAGRAM

## ANKER

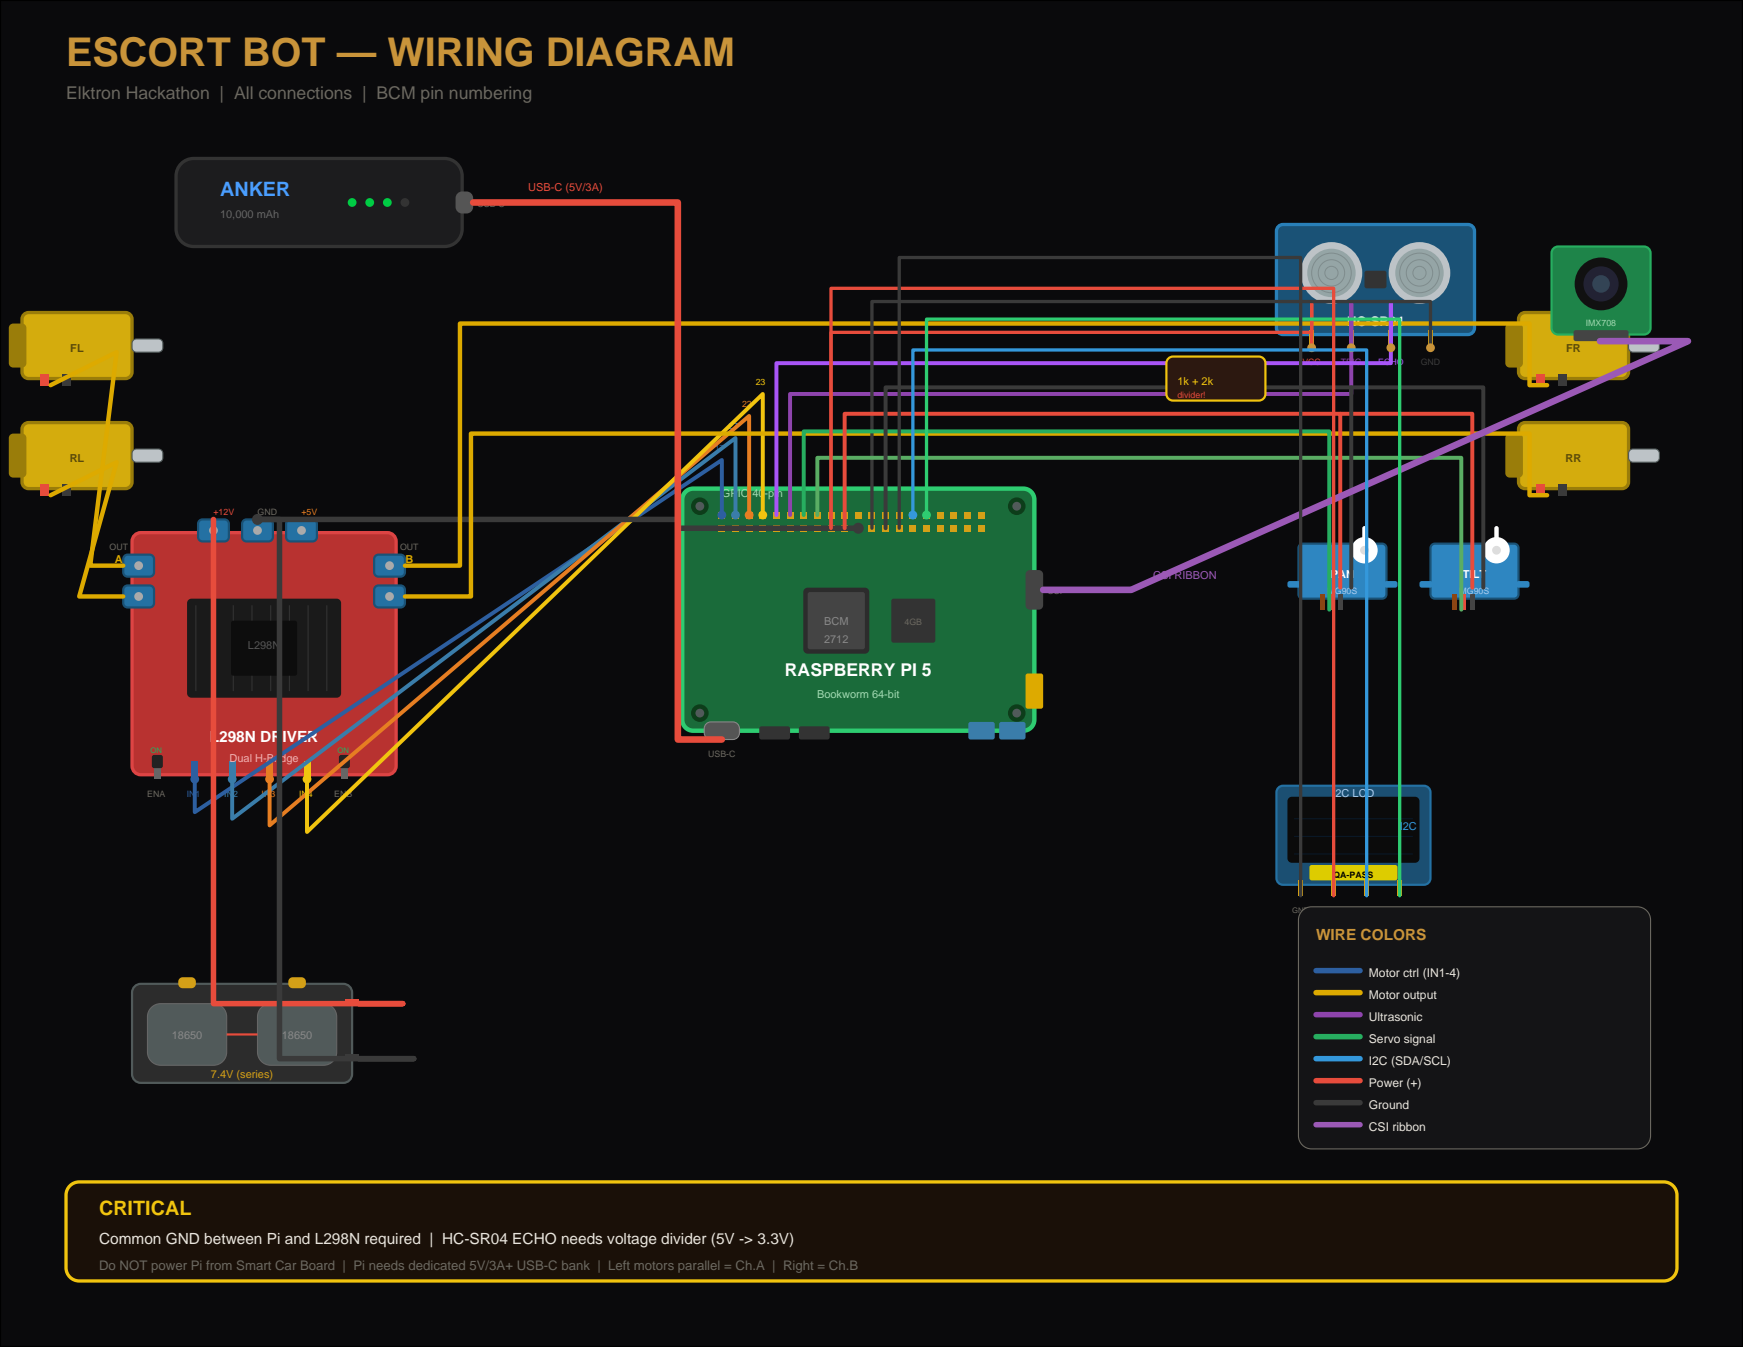
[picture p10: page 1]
BCM 2712; GPIO 40-pin; USB-C; CSI; RASPBERRY PI 5; Bookworm 64-bit; OUT A; OUT B; GND; ENA; ENB; L298N DRIVER; Dual H-Bridge; VCC; TRIG; ECHO; PAN; TILT; IMX708; 10,000 mAh; 7.4V (series); QA-PASS; SDA; SCL; I2C LCD; CSI RIBBON; USB-C (5V/3A); divider!; WIRE COLORS; Motor ctrl (IN1-4); Motor output; Ultrasonic; Servo signal; I2C (SDA/SCL); Power (+); Ground; CSI ribbon

Elktron Hackathon | All connections | BCM pin numbering

CRITICAL
Common GND between Pi and L298N required | HC-SR04 ECHO needs voltage divider (5V -> 3.3V)
Do NOT power Pi from Smart Car Board | Pi needs dedicated 5V/3A+ USB-C bank | Left motors parallel = Ch.A | Right = Ch.B

# GPIO HEADER — PIN REFERENCE

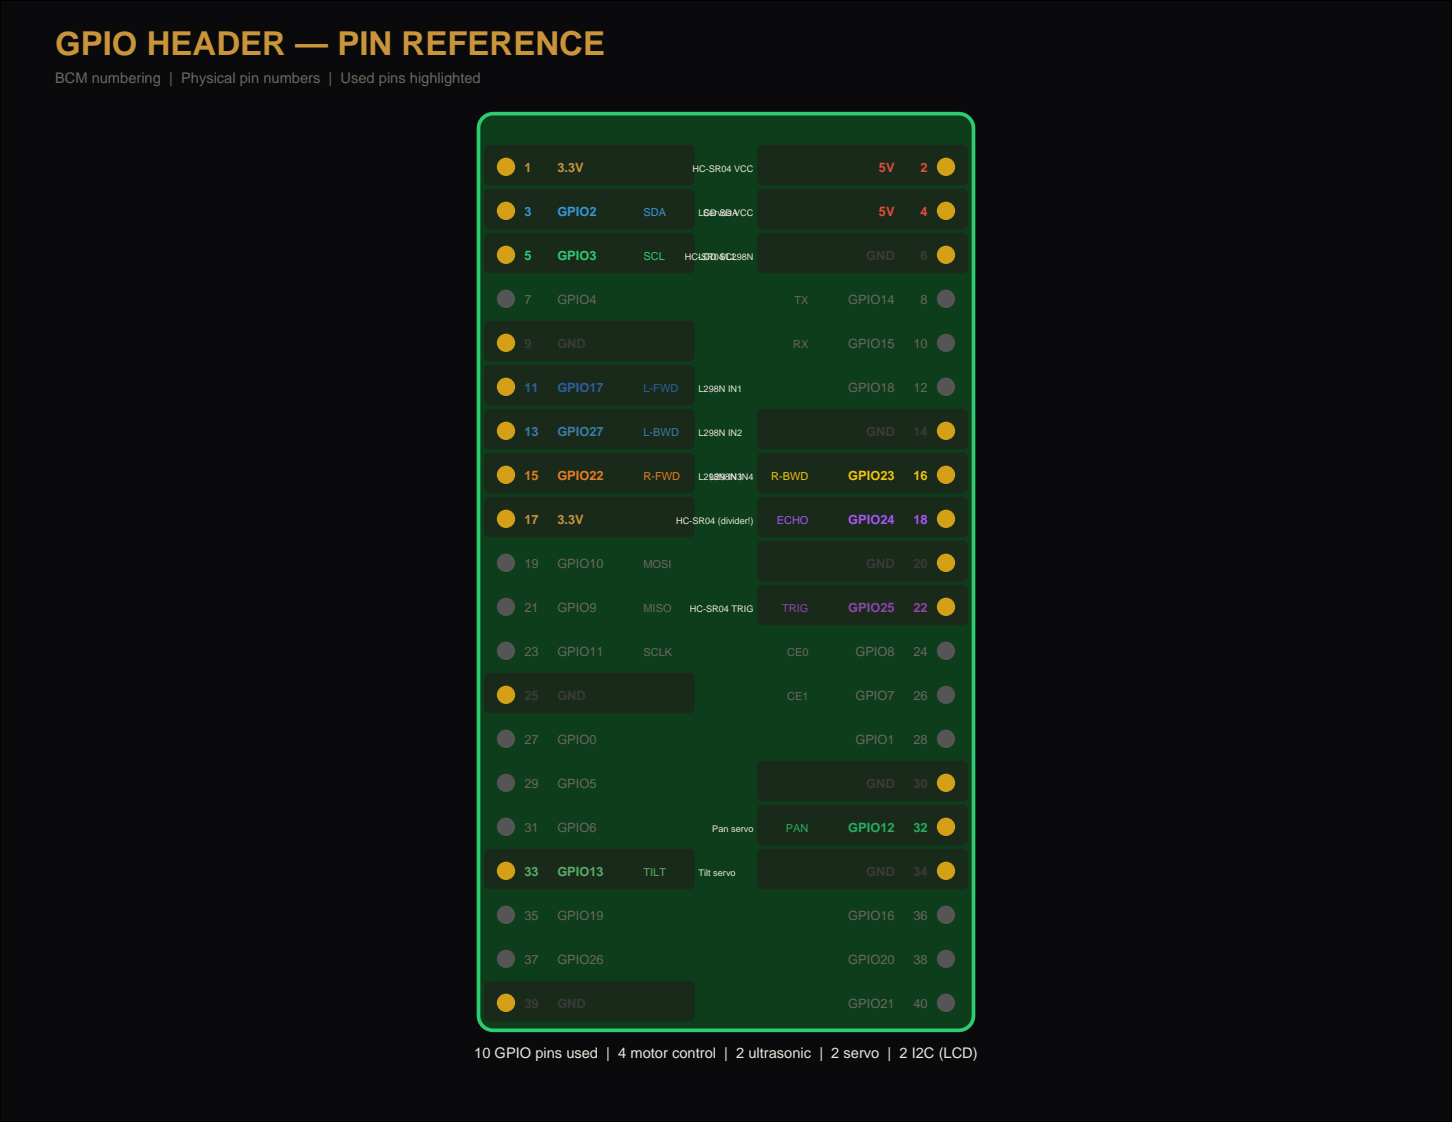
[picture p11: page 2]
GPIO2; SDA; LCD SDA; GPIO3; SCL; LCD SCL; GPIO4; 9 GND; GPIO17; L-FWD; GPIO27; L-BWD; GPIO22; R-FWD; GPIO10; MOSI; GPIO9; MISO; GPIO11; SCLK; 25 GND; GPIO0; GPIO5; GPIO6; GPIO13; TILT; Tilt servo; GPIO19; GPIO26; 39 GND; HC-SR04 VCC; Servos VCC; GND; GPIO14; GPIO15; GPIO18; R-BWD; GPIO23; HC-SR04 (divider!); ECHO; GPIO24; HC-SR04 TRIG; TRIG; GPIO25; GPIO8; GPIO7; GPIO1; Pan servo; PAN; GPIO12; GPIO16; GPIO20; GPIO21

BCM numbering | Physical pin numbers | Used pins highlighted

10 GPIO pins used | 4 motor control | 2 ultrasonic | 2 servo | 2 I2C (LCD)

# POWER DISTRIBUTION

### Two independent sources | Never cross them | Common GND required

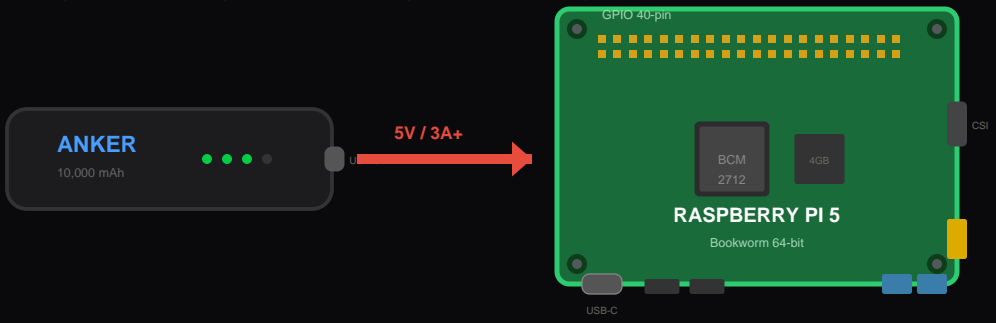
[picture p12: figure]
ANKER; 10,000 mAh; USB-C; BCM 2712; GPIO 40-pin; CSI; RASPBERRY PI 5; Bookworm 64-bit

Pi 5V rail feeds:

HC-SR04 VCC (via 5V pin)
Pan servo VCC (~150mA)
Tilt servo VCC (~150mA)
Camera (CSI, internal)

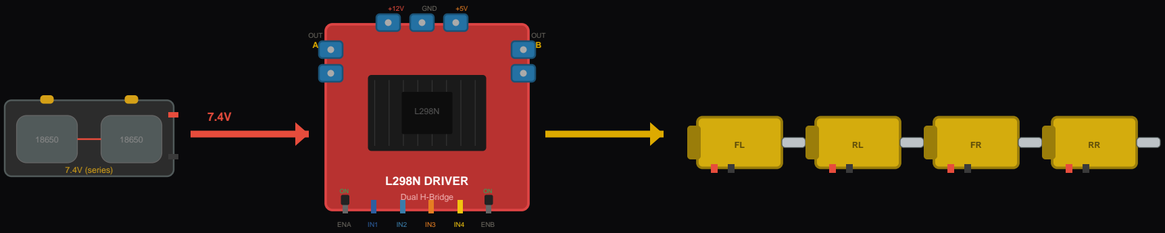
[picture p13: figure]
7.4V (series); OUT A; OUT B; GND; ENA; ENB; L298N DRIVER; Dual H-Bridge

# COMMON GROUND — MANDATORY

Pi GND (Pin 6) must connect to L298N GND terminal. Without this, GPIO signals have no reference.

Both power sources share ground through this single wire. Diagram above shows separate sources but shared GND.

## DO NOT power Pi from Smart Car Board 5V regulator

The onboard 5V regulator cannot supply 3A+ that Pi 5 needs under OpenCV load. Use a dedicated USB-C power bank.

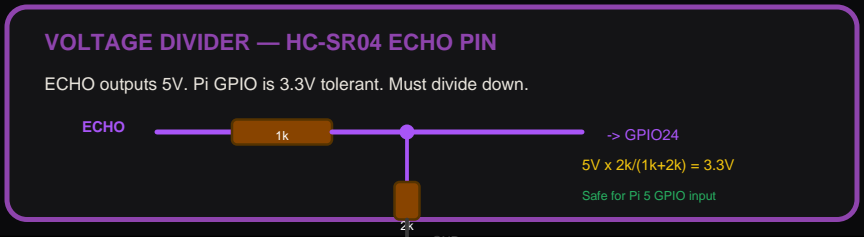
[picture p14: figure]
VOLTAGE DIVIDER — HC-SR04 ECHO PIN; ECHO; -> GPIO24; GND; Safe for Pi 5 GPIO input

ECHO outputs 5V. Pi GPIO is 3.3V tolerant. Must divide down.

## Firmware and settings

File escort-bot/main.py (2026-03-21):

#!/usr/bin/env python3
"""
Elktron Escort Bot — Person-Following Robot + Rack Scanner
Hackathon March 2026 | CoreWeave DCT

Pi 5 + LK-COKOINO 4WD + YOLO11n (ultralytics) + Arducam IMX708 Wide
Follows a vendor on the DC floor, stops at racks to scan top-to-bottom.

Modes:
  FOLLOW  — track and follow a person (vendor escort)
  SCAN    — stopped at a rack, sweep camera bottom→top capturing frames
  IDLE    — no person detected, waiting
"""

import os
import time
import argparse
import numpy as np
import cv2
from datetime import datetime
from gpiozero import Robot, DistanceSensor
from pan_tilt import PanTilt
from pid import PIDController

# ─── CONFIG ────────────────────────────────────────────────────────
MODEL_NAME = "yolo11n.pt"    # smallest ultralytics model — auto-downloads on first run
INFER_SIZE = 320             # input resolution — half of 640 = 4× faster, enough for follow
CONFIDENCE_THRESHOLD = 0.5   # Min detection confidence
FRAME_WIDTH = 640
FRAME_HEIGHT = 480

# Motor GPIO pins (BCM) — single L298N drives all 4 motors as 2 parallel pairs
# Channel A (OUT1/OUT2): FL+RL in parallel — left pair
# Channel B (OUT3/OUT4): FR+RR in parallel — right pair
LEFT_MOTOR = (17, 24)       # IN1/IN2 (forward, backward)
RIGHT_MOTOR = (22, 23)      # IN3/IN4 (forward, backward)

# Ultrasonic sensor pins (BCM)
ULTRASONIC_ECHO = 26
ULTRASONIC_TRIG = 25

# Steering
BASE_SPEED = 0.5            # 0.0–1.0
STOP_DISTANCE = 0.30        # meters — stop if obstacle closer than this
TARGET_AREA_RATIO = 0.15    # target bbox area / frame area (how close to follow)
LOST_TIMEOUT = 1.5          # seconds with no detection before stopping

# PID — Lateral (steering: keeps person centered in frame)
KP_LATERAL = 1.0            # Proportional — immediate turn response
KI_LATERAL = 0.1            # Integral — eliminates steady drift
KD_LATERAL = 0.3            # Derivative — dampens oscillation
MAX_INTEGRAL_LATERAL = 0.5  # Anti-windup clamp

# PID — Distance (speed: keeps person at target follow distance)
KP_DISTANCE = 1.2           # Proportional — speed up/slow down
KI_DISTANCE = 0.05          # Integral — eliminates steady-state gap
KD_DISTANCE = 0.2           # Derivative — smooth braking
MAX_INTEGRAL_DISTANCE = 0.3 # Anti-windup clamp

# Feed-forward
KFF = 0.15                  # Feed-forward gain — predict target motion

# Scan mode
SCAN_TRIGGER_DISTANCE = 0.50  # meters — if person stops near rack, trigger scan
SCAN_IDLE_TIME = 3.0          # seconds person must be stationary to trigger scan
SCAN_OUTPUT_DIR = "scans"     # where captured frames are saved

# Bot modes
MODE_FOLLOW = "FOLLOW"
MODE_SCAN = "SCAN"
MODE_IDLE = "IDLE"

# ─── SETUP ─────────────────────────────────────────────────────────

STREAM_URL = "http://localhost:8888/video_feed"

def init_camera():
    """Connect to the dashboard MJPEG stream instead of opening picamera2 directly.
    This lets the dashboard server and main.py share the camera without conflict."""
    cap = cv2.VideoCapture(STREAM_URL)
    if not cap.isOpened():
        raise RuntimeError(
            f"Cannot connect to camera stream at {STREAM_URL}\n"
            "Make sure the dashboard server is running: sudo systemctl start elktron"
        )
    print(f"[Camera] Connected to MJPEG stream at {STREAM_URL}")
    return cap


def init_detector():
    """Load YOLO11n — auto-downloads ~5MB on first run."""
    from ultralytics import YOLO
    model = YOLO(MODEL_NAME)
    # Warm-up pass so first real frame isn't slow
    dummy = np.zeros((FRAME_HEIGHT, FRAME_WIDTH, 3), dtype=np.uint8)
    model(dummy, imgsz=INFER_SIZE, classes=[0], verbose=False)
    print(f"[Detector] YOLO11n ready (imgsz={INFER_SIZE}, person-only)")
    return model


def init_robot():
    """Initialize motors and ultrasonic sensor."""
    robot = Robot(left=LEFT_MOTOR, right=RIGHT_MOTOR)
    sonar = DistanceSensor(echo=ULTRASONIC_ECHO, trigger=ULTRASONIC_TRIG)
    return robot, sonar


# ─── DETECTION ─────────────────────────────────────────────────────

def detect_person(frame, model):
    """
    Run YOLO11n inference on a frame.
    Returns the largest person bounding box as (x, y, w, h) in pixels,
    or None if no person detected above CONFIDENCE_THRESHOLD.
    """
    results = model(frame, imgsz=INFER_SIZE, classes=[0],
                    conf=CONFIDENCE_THRESHOLD, verbose=False)

    best_box = None
    best_area = 0

    for box in results[0].boxes:
        x1, y1, x2, y2 = map(int, box.xyxy[0])
        w, h = x2 - x1, y2 - y1
        area = w * h
        if area > best_area:
            best_area = area
            best_box = (x1, y1, w, h)

    return best_box


# ─── STEERING ──────────────────────────────────────────────────────

def compute_steering(bbox, lateral_pid, distance_pid, dt, prev_bbox=None):
    """
    PID-based steering with feed-forward.

    Two PID loops:
      1. Lateral — error = how far person is from frame center (steering)
      2. Distance — error = target area ratio - actual area ratio (speed)

    Feed-forward: uses frame-to-frame bbox center delta to predict
    where the person is heading, reducing tracking lag.

    Returns (left_speed, right_speed) each in range [-1, 1].
    """
    x, y, w, h = bbox
    person_center_x = x + w / 2
    frame_center_x = FRAME_WIDTH / 2

    # ── Lateral PID (steering) ──
    lateral_error = (person_center_x - frame_center_x) / FRAME_WIDTH
    steering = lateral_pid.update(lateral_error, dt)

    # ── Distance PID (speed) ──
    area_ratio = (w * h) / (FRAME_WIDTH * FRAME_HEIGHT)
    distance_error = TARGET_AREA_RATIO - area_ratio  # positive = too far, go forward
    speed = distance_pid.update(distance_error, dt)

    # Clamp speed to [0, BASE_SPEED] — no reversing toward person
    speed = max(0.0, min(BASE_SPEED, speed))

    # ── Feed-forward (predict target motion) ──
    ff = 0.0
    if prev_bbox is not None:
        px, py, pw, ph = prev_bbox
        prev_center_x = px + pw / 2
        delta_x = (person_center_x - prev_center_x) / FRAME_WIDTH
        ff = KFF * delta_x  # positive = person moving right

    # ── Combine into differential drive ──
    turn = steering + ff
    left_speed = max(-1.0, min(1.0, speed + turn))
    right_speed = max(-1.0, min(1.0, speed - turn))

    return left_speed, right_speed


def drive(robot, left_speed, right_speed):
    """Send speed commands to motors."""
    robot.value = (left_speed, right_speed)


# ─── SCAN MODE ─────────────────────────────────────────────────────

def run_scan(camera, pan_tilt, scan_id):
    """
    Execute a full rack scan: sweep camera bottom→top, capture a frame
    at each tilt position, save to disk.

    Returns list of saved file paths.
    """
    scan_dir = os.path.join(SCAN_OUTPUT_DIR, scan_id)
    os.makedirs(scan_dir, exist_ok=True)
    saved_files = []

    def capture_at_position(tilt_angle):
        """Callback: grab a frame and save it."""
        time.sleep(0.2)  # let servo settle
        ret, frame = camera.read()
        if not ret:
            print(f"  [WARN] Frame grab failed at {tilt_angle}°, skipping")
            return
        filename = f"rack_{tilt_angle:+04d}deg.jpg"
        filepath = os.path.join(scan_dir, filename)

        # Save as JPEG using picamera2's built-in helper
        try:
            from PIL import Image
            img = Image.fromarray(frame)
            img.save(filepath, quality=90)
            saved_files.append(filepath)
            print(f"  [CAPTURE] {filepath}")
        except ImportError:
            # Fallback: save raw numpy
            np.save(filepath.replace(".jpg", ".npy"), frame)
            saved_files.append(filepath.replace(".jpg", ".npy"))
            print(f"  [CAPTURE] {filepath} (numpy fallback — install Pillow for JPEG)")

    print(f"[SCAN] Starting rack scan — ID: {scan_id}")
    pan_tilt.scan_rack(on_position=capture_at_position)
    print(f"[SCAN] Done — {len(saved_files)} frames saved to {scan_dir}/")

    return saved_files


def person_is_stationary(bbox, prev_bbox, threshold=20):
    """Check if person bbox center hasn't moved much between frames."""
    if prev_bbox is None:
        return False
    cx = bbox[0] + bbox[2] / 2
    cy = bbox[1] + bbox[3] / 2
    pcx = prev_bbox[0] + prev_bbox[2] / 2
    pcy = prev_bbox[1] + prev_bbox[3] / 2
    return abs(cx - pcx) < threshold and abs(cy - pcy) < threshold


# ─── MAIN LOOP ─────────────────────────────────────────────────────

def main():
    parser = argparse.ArgumentParser(description="Elktron Escort Bot")
    parser.add_argument("--simulate", action="store_true", help="Simulate servos (no hardware)")
    parser.add_argument("--scan-only", action="store_true", help="Run one rack scan and exit")
    args = parser.parse_args()

    print("[Elktron] Initializing escort bot...")
    camera = init_camera()
    net = init_detector()
    robot, sonar = init_robot()
    pan_tilt = PanTilt(simulate=args.simulate)
    os.makedirs(SCAN_OUTPUT_DIR, exist_ok=True)

    # PID controllers
    lateral_pid = PIDController(
        kp=KP_LATERAL, ki=KI_LATERAL, kd=KD_LATERAL,
        max_integral=MAX_INTEGRAL_LATERAL, max_output=1.0
    )
    distance_pid = PIDController(
        kp=KP_DISTANCE, ki=KI_DISTANCE, kd=KD_DISTANCE,
        max_integral=MAX_INTEGRAL_DISTANCE, max_output=BASE_SPEED
    )

    # Scan-only mode for testing
    if args.scan_only:
        scan_id = datetime.now().strftime("scan_%Y%m%d_%H%M%S")
        run_scan(camera, pan_tilt, scan_id)
        pan_tilt.cleanup()
        camera.release()
        return

    # State tracking
    mode = MODE_IDLE
    last_seen = time.time()
    prev_bbox = None
    stationary_since = None
    scan_count = 0
    last_time = time.time()

    # Center camera for follow mode
    pan_tilt.center()

    print("[Elktron] Ready. Modes: FOLLOW → SCAN → FOLLOW")
    print(f"  Scan triggers when person is stationary for {SCAN_IDLE_TIME}s")

    try:
        while True:
            ret, frame = camera.read()
            if not ret:
                print("[WARN] Stream frame drop, retrying...")
                time.sleep(0.05)
                continue
            now = time.time()
            dt = now - last_time
            last_time = now

            # ── Obstacle override (all modes) ──
            if sonar.distance < STOP_DISTANCE:
                robot.stop()
                print(f"[STOP] Obstacle at {sonar.distance:.2f}m")
                time.sleep(0.1)
                continue

            # ── Detect person ──
            bbox = detect_person(frame, net)

            if bbox is not None:
                last_seen = time.time()

                # Check if person is stationary (potential scan trigger)
                if person_is_stationary(bbox, prev_bbox):
                    if stationary_since is None:
                        stationary_since = time.time()
                    idle_duration = time.time() - stationary_since

                    # Person has been still long enough — trigger scan
                    if idle_duration >= SCAN_IDLE_TIME and mode != MODE_SCAN:
                        robot.stop()
                        mode = MODE_SCAN
                        scan_count += 1
                        scan_id = datetime.now().strftime(f"scan_%Y%m%d_%H%M%S_{scan_count:03d}")
                        print(f"\n[MODE] FOLLOW → SCAN (person stationary {idle_duration:.1f}s)")

                        run_scan(camera, pan_tilt, scan_id)

                        # Return camera to center for follow mode
                        pan_tilt.center()
                        mode = MODE_FOLLOW
                        lateral_pid.reset()
                        distance_pid.reset()
                        stationary_since = None
                        print(f"[MODE] SCAN → FOLLOW\n")
                        continue
                else:
                    stationary_since = None

                # Normal follow mode
                mode = MODE_FOLLOW
                left, right = compute_steering(bbox, lateral_pid, distance_pid, dt, prev_bbox)
                drive(robot, left, right)
                x, y, w, h = bbox
                print(f"[FOLLOW] person@({x},{y}) size={w}x{h} → L={left:.2f} R={right:.2f}")

                prev_bbox = bbox

            else:
                # No person detected
                prev_bbox = None
                stationary_since = None
                elapsed = time.time() - last_seen

                if elapsed > LOST_TIMEOUT:
                    robot.stop()
                    if mode != MODE_IDLE:
                        print(f"[MODE] {mode} → IDLE")
                        mode = MODE_IDLE
                        lateral_pid.reset()
                        distance_pid.reset()
                else:
                    print(f"[SEARCH] Lost person, waiting {LOST_TIMEOUT - elapsed:.1f}s...")

            time.sleep(0.05)  # ~20 FPS cap

    except KeyboardInterrupt:
        print("\n[Elktron] Shutting down.")
    finally:
        robot.stop()
        pan_tilt.cleanup()
        camera.release()
        print(f"[Elktron] {scan_count} rack scans completed this session.")


if __name__ == "__main__":
    main()

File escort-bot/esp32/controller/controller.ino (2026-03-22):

/*
 * ESP-NOW Controller — Escort Bot
 * ================================
 * ESP32-CAM #1: Handheld controller with 5 buttons.
 * Sends drive commands to receiver via ESP-NOW (~5ms latency, ~200m range).
 *
 * WIRING (buttons connect pin to GND, using internal pullup):
 *   GPIO 13 → Forward button  → GND
 *   GPIO 15 → Backward button → GND
 *   GPIO 14 → Left button     → GND
 *   GPIO 2  → Right button    → GND
 *   GPIO 4  → Turbo button    → GND
 *
 * Boot notes:
 *   - GPIO 12 avoided (must be LOW at boot or enters wrong flash voltage)
 *   - GPIO 0 avoided (boot mode select)
 *   - GPIO 15 has internal pullup by default (safe for boot)
 *
 * SETUP:
 *   1. Flash this sketch via ESP32-CAM-MB programmer
 *   2. First flash get_mac.ino to find receiver's MAC address
 *   3. Replace RECEIVER_MAC below with actual MAC
 *   4. Re-flash this sketch
 */

#include <esp_now.h>
#include <WiFi.h>

// *** REPLACE WITH RECEIVER ESP32-CAM MAC ADDRESS ***
uint8_t RECEIVER_MAC[] = {0xFF, 0xFF, 0xFF, 0xFF, 0xFF, 0xFF};

// Button pins (active LOW — press connects to GND)
#define PIN_FWD   13
#define PIN_BACK  15
#define PIN_LEFT  14
#define PIN_RIGHT  2
#define PIN_TURBO  4

// Send rate (ms) — 50ms = 20Hz, fast enough for RC control
#define SEND_INTERVAL 50

// Command packet — must match receiver struct exactly
typedef struct {
  int8_t forward;  // -1 back, 0 stop, 1 forward
  int8_t turn;     // -1 left, 0 straight, 1 right
  uint8_t turbo;   // 0 normal, 1 turbo
  uint8_t estop;   // 0 normal, 1 emergency stop (no buttons = stop)
} ControlPacket;

ControlPacket packet;
esp_now_peer_info_t peerInfo;
unsigned long lastSend = 0;
bool peerAdded = false;

// Delivery callback — blink onboard LED on success
void onSent(const uint8_t *mac, esp_now_send_status_t status) {
  if (status == ESP_NOW_SEND_SUCCESS) {
    digitalWrite(33, LOW);  // ESP32-CAM onboard red LED (active LOW)
  } else {
    digitalWrite(33, HIGH);
  }
}

void setup() {
  Serial.begin(115200);
  Serial.println("\n[CTRL] ESP-NOW Controller starting...");

  // Button pins — internal pullup, press = LOW
  pinMode(PIN_FWD, INPUT_PULLUP);
  pinMode(PIN_BACK, INPUT_PULLUP);
  pinMode(PIN_LEFT, INPUT_PULLUP);
  pinMode(PIN_RIGHT, INPUT_PULLUP);
  pinMode(PIN_TURBO, INPUT_PULLUP);

  // Onboard LED (GPIO 33, active LOW)
  pinMode(33, OUTPUT);
  digitalWrite(33, HIGH); // off

  // Init WiFi in station mode (required for ESP-NOW)
  WiFi.mode(WIFI_STA);
  WiFi.disconnect();
  Serial.print("[CTRL] MAC: ");
  Serial.println(WiFi.macAddress());

  // Init ESP-NOW
  if (esp_now_init() != ESP_OK) {
    Serial.println("[CTRL] ESP-NOW init FAILED");
    return;
  }
  esp_now_register_send_cb(onSent);

  // Register receiver as peer
  memcpy(peerInfo.peer_addr, RECEIVER_MAC, 6);
  peerInfo.channel = 0; // use current channel
  peerInfo.encrypt = false;

  if (esp_now_add_peer(&peerInfo) == ESP_OK) {
    peerAdded = true;
    Serial.println("[CTRL] Peer added OK");
  } else {
    Serial.println("[CTRL] Failed to add peer");
  }

  Serial.println("[CTRL] Ready — press buttons to drive");
}

void loop() {
  if (!peerAdded) return;

  unsigned long now = millis();
  if (now - lastSend < SEND_INTERVAL) return;
  lastSend = now;

  // Read buttons (LOW = pressed due to INPUT_PULLUP)
  bool fwd   = !digitalRead(PIN_FWD);
  bool back  = !digitalRead(PIN_BACK);
  bool left  = !digitalRead(PIN_LEFT);
  bool right = !digitalRead(PIN_RIGHT);
  bool turbo = !digitalRead(PIN_TURBO);

  // Build packet
  packet.forward = 0;
  packet.turn = 0;
  packet.turbo = turbo ? 1 : 0;
  packet.estop = 0;

  if (fwd && !back)       packet.forward = 1;
  else if (back && !fwd)  packet.forward = -1;

  if (left && !right)     packet.turn = -1;
  else if (right && !left) packet.turn = 1;

  // No buttons at all = stop (not estop, just idle)
  // estop could be triggered by holding both fwd+back simultaneously
  if (fwd && back) {
    packet.forward = 0;
    packet.turn = 0;
    packet.estop = 1;
  }

  // Send
  esp_now_send(RECEIVER_MAC, (uint8_t *)&packet, sizeof(packet));
}

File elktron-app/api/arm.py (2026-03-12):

"""
Elktron Dashboard — SO-ARM101 Interface
Wraps LeRobot's Feetech motor bus for reading joint state and sending commands.
Falls back to mock data when hardware is not connected.
"""

import logging
import time
from typing import Optional

from models import ArmPhase, ArmState, GripperState, JointAngles

logger = logging.getLogger("elktron.arm")

# Servo IDs on the Feetech bus (STS3215, daisy-chained via BusLinker V3.0)
SERVO_IDS = {
    "base": 1,
    "shoulder": 2,
    "elbow": 3,
    "wrist_pitch": 4,
    "wrist_roll": 5,
    "wrist_yaw": 6,
}

# Home position (degrees) — arm straight up, gripper open
HOME_POSITION = {name: 0.0 for name in SERVO_IDS}

# Serial config
DEFAULT_PORT = "/dev/ttyACM0"
BAUDRATE = 1_000_000  # Feetech STS3215 default


class ArmInterface:
    """Interface to SO-ARM101 via LeRobot's Feetech motor bus."""

    def __init__(self, port: str = DEFAULT_PORT):
        self.port = port
        self._bus = None
        self._connected = False
        self._phase = ArmPhase.idle
        self._gripper = GripperState.open
        self._holding_optic = False
        self._cycle_count = 0
        self._error: Optional[str] = None

    @property
    def connected(self) -> bool:
        return self._connected

    def connect(self) -> bool:
        """Connect to the arm via USB serial. Returns True on success."""
        try:
            from lerobot.common.robot_devices.motors.feetech import FeetechMotorsBus

            self._bus = FeetechMotorsBus(
                port=self.port,
                motors={name: (sid, "sts3215") for name, sid in SERVO_IDS.items()},
            )
            self._bus.connect()
            self._connected = True
            self._error = None
            logger.info(f"SO-ARM101 connected on {self.port}")
            return True
        except ImportError:
            self._error = "lerobot not installed — run: pip install lerobot"
            logger.warning(self._error)
            return False
        except Exception as e:
            self._error = f"Connection failed: {e}"
            logger.warning(self._error)
            self._connected = False
            return False

    def disconnect(self):
        """Disconnect from the arm."""
        if self._bus is not None:
            try:
                self._bus.disconnect()
            except Exception:
                pass
        self._bus = None
        self._connected = False
        logger.info("SO-ARM101 disconnected")

    def read_joints(self) -> JointAngles:
        """Read current joint positions from all 6 servos."""
        if not self._connected or self._bus is None:
            return JointAngles()

        try:
            positions = self._bus.read("Present_Position")
            names = list(SERVO_IDS.keys())
            angles = {}
            for i, name in enumerate(names):
                # Convert raw servo ticks to degrees
                # STS3215: 0-4095 ticks = 0-360 degrees, center at 2048
                raw = positions[i] if i < len(positions) else 2048
                angles[name] = round((raw - 2048) * (360.0 / 4096.0), 1)
            return JointAngles(**angles)
        except Exception as e:
            logger.error(f"Failed to read joints: {e}")
            return JointAngles()

    def read_temperature(self) -> float:
        """Read average servo temperature (Celsius)."""
        if not self._connected or self._bus is None:
            return 25.0

        try:
            temps = self._bus.read("Present_Temperature")
            return round(sum(temps) / len(temps), 1)
        except Exception:
            return 25.0

    def read_load(self) -> float:
        """Read average servo torque load."""
        if not self._connected or self._bus is None:
            return 0.0

        try:
            loads = self._bus.read("Present_Load")
            return round(sum(abs(l) for l in loads) / len(loads), 1)
        except Exception:
            return 0.0

    def go_home(self):
        """Move all joints to home position."""
        if not self._connected or self._bus is None:
            return

        try:
            positions = [2048] * len(SERVO_IDS)  # Center position for all servos
            self._bus.write("Goal_Position", positions)
            self._phase = ArmPhase.retracting
            logger.info("Arm moving to home position")
        except Exception as e:
            logger.error(f"Failed to go home: {e}")

    def set_gripper(self, state: GripperState):
        """Open or close the gripper (wrist_yaw servo)."""
        if not self._connected or self._bus is None:
            return

        try:
            grip_id = SERVO_IDS["wrist_yaw"]
            if state == GripperState.open:
                target = 2048 + 512  # Open position
            else:
                target = 2048 - 512  # Closed position
            self._bus.write("Goal_Position", [target], motor_names=["wrist_yaw"])
            self._gripper = state
        except Exception as e:
            logger.error(f"Failed to set gripper: {e}")

    def get_state(self) -> ArmState:
        """Get complete arm state for dashboard broadcast."""
        joints = self.read_joints()
        temp = self.read_temperature()
        torque = self.read_load()

        return ArmState(
            phase=self._phase,
            gripper=self._gripper,
            holding_optic=self._holding_optic,
            joints=joints,
            torque_avg=torque,
            temp_c=temp,
            cycle_count=self._cycle_count,
            accuracy_mm=0.8,  # Placeholder — updated after calibration
            connected=self._connected,
            port=self.port if self._connected else None,
            error=self._error,
        )

    def handle_command(self, action: str, **kwargs):
        """Handle a command from the dashboard."""
        if action == "home":
            self.go_home()
        elif action == "calibrate":
            self._phase = ArmPhase.calibrating
            self.go_home()
            time.sleep(2)
            self._phase = ArmPhase.idle
        elif action == "stop":
            if self._bus and self._connected:
                try:
                    self._bus.write("Torque_Enable", [0] * len(SERVO_IDS))
                except Exception:
                    pass
            self._phase = ArmPhase.idle
        elif action == "start_task":
            task = kwargs.get("task", "optic_seating")
            self._phase = ArmPhase.reaching
            logger.info(f"Starting task: {task}")
        else:
            logger.warning(f"Unknown arm command: {action}")


# Singleton — import and use directly
arm = ArmInterface()

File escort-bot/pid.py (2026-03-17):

#!/usr/bin/env python3
"""
PID Controller — generic, reusable, no hardware dependencies.

Used by the escort bot for:
  1. Lateral PID  — keeps person centered in frame (steering)
  2. Distance PID — keeps person at target follow distance (speed)

Theory:
  output = Kp * error + Ki * integral(error) + Kd * d(error)/dt

  Anti-windup: integral clamped to [-max_integral, +max_integral]
  Derivative filter: exponential moving average (alpha) to reduce bbox jitter
  Output clamp: final value clamped to [-max_output, +max_output]
"""


class PIDController:
    def __init__(self, kp=1.0, ki=0.0, kd=0.0,
                 max_integral=1.0, max_output=1.0,
                 d_filter_alpha=0.3):
        """
        Args:
            kp: Proportional gain — immediate response to error
            ki: Integral gain — eliminates steady-state offset
            kd: Derivative gain — dampens overshoot
            max_integral: Anti-windup clamp for integral accumulator
            max_output: Clamp for final output
            d_filter_alpha: Low-pass filter for derivative (0-1, lower = smoother)
        """
        self.kp = kp
        self.ki = ki
        self.kd = kd
        self.max_integral = max_integral
        self.max_output = max_output
        self.d_filter_alpha = d_filter_alpha

        # State
        self._integral = 0.0
        self._prev_error = 0.0
        self._filtered_derivative = 0.0
        self._first_update = True

    def update(self, error, dt):
        """
        Compute PID output for the given error and timestep.

        Args:
            error: setpoint - measurement (positive = need to move right/forward)
            dt: time since last update in seconds

        Returns:
            Clamped PID output in [-max_output, +max_output]
        """
        # ── Proportional ──
        p_term = self.kp * error

        # ── Integral (with anti-windup) ──
        if dt > 0:
            self._integral += error * dt
            self._integral = max(-self.max_integral,
                                 min(self.max_integral, self._integral))
        i_term = self.ki * self._integral

        # ── Derivative (with low-pass filter) ──
        if dt > 0 and not self._first_update:
            raw_derivative = (error - self._prev_error) / dt
            self._filtered_derivative = (
                self.d_filter_alpha * raw_derivative +
                (1.0 - self.d_filter_alpha) * self._filtered_derivative
            )
        d_term = self.kd * self._filtered_derivative

        self._prev_error = error
        self._first_update = False

        # ── Sum and clamp ──
        output = p_term + i_term + d_term
        return max(-self.max_output, min(self.max_output, output))

    def reset(self):
        """Clear all accumulated state."""
        self._integral = 0.0
        self._prev_error = 0.0
        self._filtered_derivative = 0.0
        self._first_update = True

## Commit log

2026-03-10 Focus repo + optimize + update content
    [optic-staging-tray.obj]
2026-03-12 Full repo sync — rename to Elktron, add all components, remove floorcrew
    - Remove floorcrew-app/ and floorcrew-robots.blend (old name)
    - Add elktron-app/ (FastAPI dashboard + WebSocket server)
    - Add escort-bot/ new files (simulation, assembly, hardware pages, pan_tilt, Soldier.glb)
    - Add CKK0011-main/ (vendor chassis kit — tutorials, drivers, Pi code)
    - Add 2d_manual_3d/, 3d-reference/, img/, reference/, taskboard/
    - Add design-system.css (shared CoreWeave white + blue tokens)
    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
    [elktron-robots.blend]
2026-03-12 Remove floorcrew-app/ (replaced by elktron-app/)
    [arm.py, escort.py, models.py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]
2026-03-16 Add interactive wiring guide, PDF diagram generator, and label tools
    - Rewrite wiring-guide.html as interactive SVG diagram with CoreWeave design system
    - Add generate_wiring_pdf.py for printable wiring reference (3-page PDF)
    - Add P-Touch label generation scripts for wire labeling
    - Update assembly.html with locked regions and 3D improvements
2026-03-16 Redesign index — CoreWeave white theme + Three.js hero
    White background, Plus Jakarta Sans, CW blue (#2741E7) accent.
    Three.js wireframe icosahedron hero with mouse parallax, orbiting
    dot, drifting particles. Staggered scroll-reveal cards. Frosted
    nav bar. Responsive + prefers-reduced-motion support.
2026-03-16 Maximalist 3D redesign — full Three.js background with bloom, particles, orbital rings
    Full-viewport Three.js canvas with UnrealBloomPass post-processing, wireframe icosahedron
    with pulsing vertex nodes, 3 orbital rings with traveling dots, 120 floating particles,
    data stream tubes, CSS scanning line + grid overlay, mouse parallax, scroll-driven camera
    drift, and per-card float animations. CoreWeave white theme with blue accent.
2026-03-16 Taskboard: white topbar + staggered entrance animations
    - Topbar: dark navy → white with border, blue accent on active tab
    - Toast: dark → white with border to match theme
    - Added entrance animations: topbar slide-in, sidebar slide-in, metric pop,
    progress bar grow, phase group staggered reveals, toolbar fade-up
    - Respects prefers-reduced-motion
2026-03-16 Fix wiring guide: move FR+RR motors, add ENA/ENB note, motor basics panel
    - Move right motor node from left side to below L298N for clearer left/right separation
    - Add ENA/ENB jumper note to critical bar
    - Motor Wiring Basics collapsible SVG panel (added in previous session)
    [labels.csv]
2026-03-16 Add person detection milestone — YOLOv8n working on Pi 5 at DC floor
    - progression/: 5 camera test frames (0.78 confidence bounding boxes),
    Pi terminal output, and SCP transfer proof
    - Taskboard: mark 6 more tasks done (FC-077/078/088/089/090/092)
    - Detection model confirmed: YOLOv8n via Arducam IMX708 wide + libcamera v0.7.0
2026-03-17 Fix landing page: dead links, CSS readability, add missing pages
    - Fix hub/hub.html → hub.html, hub/daily.html → daily.html
    - Fix dashboard/ → elktron-app/ paths for dashboard and guide
    - Remove 6 cards linking to nonexistent files (3 chassis, 3 pitch)
    - Add parts-status, shopping-list, raphael-checklist to Tools section
    - Fix taskboard tag from Three.js to App
    - Darken text colors for better contrast on white background
    - Update page count stat from 25+ to 21
    - Sync root index.html with sites/index.html
    - Add motor_test.py and sonar_test.py for escort bot hardware testing
    - Update taskboard with motor wiring task completions
    [motor_test.py, sonar_test.py]
2026-03-17 Site-wide audit: fix stale model refs, team roster, Three.js versions
    - Replace 60+ TFLite/MobileNet SSD references with YOLOv8n across 13 files
    - Replace Alex Murillo with Raphael Rodea in 6 files (daily, parts-status,
    raphael-checklist, shopping-list, robotics-site/index, taskboard)
    - Standardize Three.js from v0.162/v0.163 to v0.170.0 across 6 files
    - Update topology.html detection pipeline details (camera, model, accuracy)
    - Update assembly.html terminal simulation (ultralytics install flow)
    - Fix raphael-checklist partner from Alex to Josh
2026-03-17 Add full hardware assembly + build photos — escort bot working at DC
    Chassis assembled, L298N wired to Pi 5 GPIO, Arducam IMX708 connected.
    YOLOv8n person detection confirmed at 78% confidence on DC floor.
    12 new build photos in progression/, updated README, PROGRESS, and
    landing page with Build Progress section showing real hardware.
2026-03-17 Add Slack 10-step checklist to PROGRESS.md — phases 1-2 done, 4-5 in progress
    Synced from #the-elks-2026 Slack list. Phase 4 (build) ~80% complete,
    Phase 5 (test) in progress — detection working, motor test next.
2026-03-17 Add demo video creative brief for Talha — story options, tone picks, shot list, template
    5 story angles (journey, problem, heist, day-in-the-life, reveal),
    3 tone options (cinematic, documentary, scrappy), shot checklist,
    and fill-in-the-blank framework. Designed for Talha to own the
    creative direction.
2026-03-17 feat(escort): add PID controller with feed-forward steering
    Replace P-only compute_steering with dual PID (lateral + distance)
    and feed-forward term. Lateral PID eliminates drift, distance PID
    smooths braking, feed-forward predicts target motion for reduced
    tracking lag. 8 unit tests, anti-windup, derivative filtering.
    [main.py, pid.py, test_pid.py]
2026-03-17 feat(assembly): GLB models, mounting step, software showcase, UX polish
    - Replace procedural pan-tilt camera and HC-SR04 with Meshy AI GLB models
    - Add HC-SR04 blue board tint for visual distinction
    - Add "Mounting & Fastening" step (12) with per-component fastener specs
    - Remove Wiring Harness step (consolidating assembly flow)
    - Replace interactive Pi Setup Quest with auto-playing Software Showcase
    that typewriter-animates the full tech stack (YOLOv8n, picamera2, etc.)
    - Save all component positions from Edit Mode (PVC mast, pan-tilt camera)
    - Hide Explode button except on final step
    - Auto-start first assembly step with cinematic slow entrance on page load
    - Update battery-pack position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
2026-03-17 chore: sync all project docs, labels, GLB assets, and site updates
    - Add Meshy AI GLB models (chassis, pan-tilt camera, HC-SR04)
    - Add label PNGs for P-touch printer (wiring, boards, orientation)
    - Update CLAUDE.md files across all subprojects
    - Update parts list, demo script, team checklist
    - Add chassis 2D/3D reference files and blueprints
    - Add topology visualizations and pitch deck
    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
2026-03-17 refactor: repo reorg + professional README redesign
    - Delete elktron-repo/ (87MB duplicate), elktron-sites.zip, CH340 Windows drivers
    - Move 11 root markdown docs to docs/ (checklists, team, velocity, etc.)
    - Organize escort-bot: tests/, tools/, assets/ subdirectories
    - Absorb reference/ into docs/reference/
    - Update CLAUDE.md topology and cross-references
    - Rewrite README with hero image, shields.io badges, side-by-side robot
    cards, interactive demo links (GitHub Pages), mermaid architecture
    diagram, collapsible BOM/structure/demo sections, team table
    [labels.csv]
2026-03-17 feat(readme): use clean 3D render for escort bot image
    Captured from assembly.html at step 11 (all physical components,
    no monitor overlay) with UI hidden. Clean 3/4 angle showing full
    chassis, mast, and pan-tilt camera.
2026-03-17 refactor: consolidate reference files + add link mesh test
    Move 171 unreferenced files (labels, chassis photos, PDFs, Blender
    source, progression dupes) into reference/ directory. Fix 26 broken
    asset references found by new link mesh validator across 4 files
    (sites/index.html, escort-bot/showcase.html, docs/PARTS-LIST.md,
    romeo-ops.html).
    Add tests/test_link_mesh.py — scans all HTML/MD files for src, href,
    url(), .load(), fetch(), and markdown refs; validates every local path
    resolves. Includes orphan detection for img/, glb/, and progression/.
    [elktron-robots.blend, optic-staging-tray.blend]
2026-03-17 docs: add ultrasonic integration decision PDF (HC-SR04 vs Pico 2)
    10-page technical decision document comparing two paths for wiring the
    HC-SR04 ultrasonic sensor — direct voltage divider vs Pico 2 middleware.
    Includes wiring diagrams, code snippets, GPIO maps, and timeline analysis.
2026-03-17 feat(simulation): add in-browser GIF capture (press G)
    Adds preserveDrawingBuffer to WebGL renderer and a built-in frame
    recorder that encodes an animated GIF directly in the browser —
    no external deps, single-file download. Useful for demo assets.
    Also includes wiring-wizard updates from prior session.
2026-03-17 feat: add interactive wiring wizard with real pin diagrams
    14-step dumbproof wiring guide with full Pi 5 40-pin GPIO header,
    L298N board layout, HC-SR04 pins, servo connectors. Active pins
    glow, animated wire drawing, voltage divider interstitial warning,
    final verification checklist. Smooth crossfade transitions.
2026-03-17 update: wiring wizard + WIRING.md corrections
2026-03-17 fix(landing): brighten page — reduce Three.js darkness
    - Set canvas clear color to #fafbfe (was black)
    - Reduce canvas opacity to 35% so light body shows through
    - Cut bloom strength in half
    - Increase card background opacity to 0.88
    - Add white gradient backing on main content area
    - Soften scan-line overlay
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2026-03-17 cleanup: remove wiring-wizard.html (merged into wiring-guide.html), fix label-guide nav link
2026-03-18 fix: restore wiring-wizard.html for GitHub Pages URL compatibility
    The file was removed in 089a00c but the URL is still shared/linked.
    Restores it with the current wiring-guide.html content (upgraded breadboard).
2026-03-18 fix: restore original wiring-wizard.html (distinct step-by-step UI)
    Previous commit incorrectly overwrote with wiring-guide.html content.
    Restored from 935e3f7 — the warm beige wizard with breadboard steps.
2026-03-18 update: reframe narrative — escort bot primary, add live site link
    Rebalance all judge-facing materials to lead with escort bot as the
    primary demo. Arm becomes "the platform extends." README gets GitHub
    Pages link. Demo script rebalanced (75s escort, 35s arm). Pitch deck
    and landing page card order swapped. Wiring guide nodes spread out
    and Motor Basics button fixed. Wiring wizard gets motor_test.py step.
    New PROJECT-OVERVIEW.md for clean project summary.
2026-03-18 feat: 3D DC floor map + fix wiring diagram left side
    Replace flat SVG floor map in index.html with a full Three.js 3D scene:
    low flythrough camera through hot aisle, 10 extruded racks with LED
    activity lights, animated escort bot patrol, SO-101 arm with moving
    segments, bloom post-processing, fog, mouse parallax, raycaster
    hover/click interaction with tooltips.
    Fix Motor Basics diagram: left side black wires were overlapping red
    at x=260. Staggered to x=260 (red) / x=280 (black) to mirror the
    clean right side layout.
2026-03-18 fix: brighten 3D DC floor map — camera, lighting, materials
    The animate loop was overriding camera position back to (-18, 2.8, 0)
    and bloom to 0.5, ignoring initial brightness fixes. Now synced:
    - Camera: (-12, 4.5, 3) base with parallax
    - Ambient light: 1.2 intensity, directional: 1.0
    - Bloom: 0.25 base (was 0.5 in loop)
    - Tone mapping exposure: 2.0
    - Rack bodies, floor, ceiling all brightened
    - Ceiling light tubes opacity 0.2 (was 0.08)
2026-03-18 remove: 3D DC floor map from index.html
    Replaced with existing simulation.html — no need for a redundant
    inline 3D scene when the full simulation already exists as a card link.
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2026-03-18 fix: replace wrong Mecanum chassis with correct LK-COKOINO 4WD
    hardware-showcase.html had an outdated Mecanum-wheel robot with
    omnidirectional rollers. Replaced with the actual LK-COKOINO 4WD:
    - Two acrylic plates with 6 hex standoffs
    - 4x TT DC motors with 65mm rubber tires
    - Blue accent side rails and front bumper
    - Updated all text: "mecanum" → "4WD differential"
    - Shifted upper-plate components to match new geometry
2026-03-18 Replace procedural chassis with GLB model in hardware-showcase.html
    Swapped out the incorrect procedural geometry (plates, standoffs, rails,
    wheels) with the Meshy AI GLB model used in assembly.html. Added GLTFLoader
    import, auto-center/scale logic, and dynamic repositioning of upper-plate
    components (Pi 5, cooler, mast, camera, sensors) relative to the GLB
    bounding box.
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2026-03-18 fix: update hub links across 10 pages to point to index.html
    Previously linked to CodePen or hub.html — now all point to ../index.html
2026-03-18 cleanup: merge parts pages, delete obsolete pages, fix Slack refs
    - Merge parts-status.html + shopping-list.html into unified dark-themed inventory page
    with filters, checkboxes, localStorage, progress bar, and organized groups
    - Delete 6 obsolete pages: raphael-checklist, romeo-ops, chassis_frame_analysis,
    chassis_front_frame_analysis, chassis_unified_3d, chassis_2d_diagram
    - Redirect shopping-list.html and daily.html to their merged targets
    - Fix Slack channel name across 8 files: #more-better-faster-2026 → #more-faster-better-2026
    - Add #the-elks-2026 as team channel in docs/TEAM.md
    - Update index.html: add "In Construction" badge, countdown timer, remove deleted cards
    - Update site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
2026-03-18 audit: cut 25 broken/redundant pages, tighten hub to 5 phases
    Site audit found 43 HTML files — many incomplete stubs, pipeline artifacts,
    or internal dev tools that would embarrass if a judge clicked them. Cut to 18.
    Deleted (25 files):
    - 7 broken stubs: hardware.html (blank 3D), controller.html (no backend),
    3 chassis viewers (no models), wiring-wizard (duplicate), label-guide
    - 3 redirects: hub.html, daily.html, shopping-list.html
    - 15 dev tools: 3 topology pages, sites/index, pitch-playbook,
    5 img/2d_drawing pipeline files, 5 2d_manual_3d pipeline files
    Rebuilt index.html: 10 phases → 5 phases, 37 cards → 15 cards
    Fixed stale links in robotics-site/index.html, mast-hardware.ht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
2026-03-18 hub: spacious hero layout, entrance animations, compact card grid
    - Hero: two-column flex (title left, sim preview right), 65vh min-height
    - Staggered entrance animations (badge → title → text → stats → sim)
    - Transparent hero/sim backgrounds — 3D particles show through
    - Cards: tighter grid (240px min), smaller padding/fonts, denser phases
    - 3D background opacity bumped to 0.45
    - Taskboard: mark FC-075/FC-083/FC-096 done
    - Design system, docs, CLAUDE.md updates across 22 files
    [generate_ultrasonic_pdf.py]
2026-03-18 hub: rewrite as clean CW console light theme, remove Three.js
    Strip 600+ lines of Three.js 3D background, dark theme, glassmorphism,
    glow effects, and entrance animations. Replace with CW console-aligned
    light theme: sticky nav, featured cards for assembly + simulation,
    compact link-list rows grouped by phase, hardware progress photos,
    team names in footer. 880 → 301 lines.
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2026-03-18 labels: replace text placement guide with visual SVG diagrams
    Top-down view shows chassis layout with all components (Pi 5, L298N,
    HC-SR04, batteries, mast) and color-coded callout lines to each label
    position. Side view shows mast assembly with camera, pan/tilt, and
    servo wire routing. Much faster to follow during physical assembly.
2026-03-18 fix outdated hardware refs in hardware-showcase.html
    Replace all Freenove/Smart Car/MobileNet SSD/IR Tracker/Photoresistor
    references with actual hardware: LK-COKOINO CKK0011 chassis, L298N
    motor driver, YOLOv8n detection, Arducam IMX708, direct GPIO wiring.
    11 text references updated across specs, architecture, BOM, power,
    and wiring sections.
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2026-03-18 wiring-guide: replace direct servo GPIO with PTZ controller board I2C wiring + add LCD step
    PTZ board (Arducam B0283) uses I2C (GPIO 2/3, addr 0x40) instead of direct PWM on GPIO 12/13.
    Added LCD wiring step (shares I2C bus at 0x27/0x3F). Added i2cdetect verification step.
    Updated checklist, diagrams, nodes, and legend to match actual hardware.
2026-03-18 wiring-guide: fix pin conflicts — unique VCC/GND per component
    Pin audit: L298N (GND=6), HC-SR04 (VCC=2, GND=9), LCD (VCC=4, GND=14),
    PTZ Board (VCC=2, GND=20). I2C SDA/SCL shared by design. No conflicts.
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2026-03-18 wiring-guide: redesign full pin map + add breadboard I2C bus split notes
    Complete pin map: replaced overlapping labels/spaghetti lines with clean
    component-card schematic. Cards on left (LCD, PTZ, L298N) and right
    (HC-SR04, Camera, Battery, Anker) with curved wire paths to Pi header.
    Each card lists its pins inline. Wider SVG (690x345) for breathing room.
    LCD + PTZ steps now explain breadboard splitter for shared I2C SDA/SCL
    since you can't physically plug 2 wires into 1 GPIO pin.
2026-03-18 wiring-guide: fix Pin 2 5V conflict (HC-SR04 + PTZ) + checklist GND bug
    Pin 2 (5V) shared by HC-SR04 and PTZ Board — added breadboard split note.
    Fixed checklist: HC-SR04 GND was incorrectly listed as Pin 6 (L298N's),
    corrected to Pin 9. Updated step text and pin map callout.
2026-03-18 fix GPIO pin assignments across all project files
    Left Motor BWD moved from GPIO 27 (Pin 13) to GPIO 24 (Pin 18).
    Ultrasonic ECHO moved from GPIO 24 (Pin 18) to GPIO 26 (Pin 37).
    Updated 21 files: code, wiring guides, 3D pages, labels, tests, docs.
    [api_server.py, generate_ptouch_labels.py, generate_ultrasonic_pdf.py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]
2026-03-18 wiring-guide: redesign full-pinmap with all 40 pin labels + breadboard markers
    Shows every Pi 5 GPIO pin with function labels, highlights used pins
    with component colors, and marks breadboard-shared pins (SDA/SCL/5V)
    with ○ symbol. Fixes L298N IN2 pin (13→18) and adds HC-SR04 ECHO (pin 37).
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2026-03-19 wiring-guide: full-pinmap with real breadboard + Pi header reference
    Replaces BB nodes with a proper breadboard visual showing 3 bus rows
    (SDA, SCL, 5V) with holes. Layout: Pi header (left) with all 40 pins
    labeled, breadboard (center) showing shared buses + direct wire list,
    component cards (right) with wire paths from breadboard buses.
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2026-03-19 Full breadboard rendering + HC-SR04 on-board with voltage divider
    - Replace abstract 3-bus-row breadboard with full 30x4x2 breadboard (240 holes)
    - HC-SR04 plugged directly into breadboard rows 5-8 with chip outline
    - Voltage divider inline between rows 7-9 (1kΩ + 2kΩ for 5V→3.3V ECHO)
    - Remove duplicate wire paths from HC-SR04 card (now label-only since sensor is on BB)
    - Fix SVG height (580→640) to prevent voltage divider callout overlapping cards
    - Move voltage divider callout below component cards (y=360→510)
    - Column labels (a-h), row numbers (1-30), center channel, bus row highlights
2026-03-19 Fix 7 bugs in full-pinmap wiring diagram
    1. CRITICAL: Cross-channel jumper now correctly routes from col d (left)
    to col e (right), crossing the breadboard center channel
    2. Add missing 2kΩ resistor leg to voltage divider (junction→GND)
    3. Fix stats bar: 11→8 direct wires + 6 BB-routed (accurate count)
    4. Fix column labels overlapping breadboard title (y offset -5→-2)
    5. Compute L298N card Y dynamically instead of hardcoded 168
    6. Fix bus-to-card wire origin to start at col d hole, not past board edge
    7. Reword voltage divider callout for clarity (show signal path)
2026-03-19 Differentiate active vs empty breadboard holes
    Active holes: colored fill + glow ring (clearly visible)
    Empty holes: subtle square cutouts (reads as grid, doesn't compete)
    Fixes confusion where all holes looked like identical dots
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2026-03-19 Fix breadboard visual clarity — increase spacing, simplify holes
    - Increase hole spacing: 8px → 10px (row gap + col gap), channel 12→14px
    - Remove confusing glow rings from active holes — now clean colored dots
    with white outline (distinct without bloating)
    - Empty holes: small dark pits instead of square cutouts
    - SVG height 640→700 to accommodate taller breadboard
    - Move voltage divider callout down to match
    Fixes the overlapping blob issue in bus rows 1-3 where glow rings,
    thick wires, and tight spacing made everything unreadable.
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2026-03-19 Add full system wiring diagram for Pico 2 test mode
    Replaces simple pinout with complete diagram matching Pi 5 full-pinmap
    style: Pico 2 header (40 pins), breadboard with bus rows, 5 component
    cards (LCD, PTZ, L298N, HC-SR04, Battery), motor boxes, voltage divider,
    cross-channel jumper, and all wire routing (bus/direct/bbRow).
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2026-03-19 Redraw Pico 2 board and redo all wire connections
    Complete rewrite of initPico2() diagram:
    - Green PCB board (80x310) with realistic features: USB-C port,
    BOOTSEL button, RP2350 QFN chip with lead pads, crystal oscillator,
    LED, SWD debug pads, castellated half-hole edges, copper ground plane
    - Gold square pads for active pins, gold circles for unused
    - All wire connections redrawn: bus wires (SDA/SCL/5V) from Pico to
    breadboard, sensor wires (TRIG/ECHO/GND) to BB right side, direct
    wires (IN1-IN4, GND) to component cards, BB-routed wires to HC-SR04
    - Pin 40 (VBUS) uses custom bezier curve for the long bottom-to-top run
    - Layout adjusted: W=780, cards at x=430, motors at x=610
    - Silks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
2026-03-19 Add 3D shell preview + breadboard layout fixes
    - shell.scad: parametric OpenSCAD shell (260x158x105mm) with wheel
    arches, HC-SR04 holes, mast hole, vents, wire slots
    - shell.stl: exported STL for 3D printing
    - assembly.html: STL-loader shell preview with toggle button, opacity
    slider, dynamic scaling to match chassis GLB bounding box
    - wiring-guide.html: remove Pico 2 dead code (~260 lines), move
    HC-SR04 to breadboard rows 12-15 for visual clarity, move HC-SR04
    overview node to top-right corner
    [shell.scad, shell.stl]
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2026-03-19 Narrow shell to fit between tires, not over them
    - shell.scad: chassis_w 152→100mm (frame body width, not tire-to-tire)
    Shell outer width: 158.6→106.6mm — sits cleanly between 1" tires
    - shell.stl: re-exported with corrected dimensions
    - assembly.html: further reduced shell width scale factor for preview
    [shell.scad, shell.stl]
2026-03-20 Add GPIO reference files, test script, and update pin assignments
    GPIO_Current.csv and GPIO_ref.png added to escort-bot/assets.
    New gpio_test.py with pin verification and WASD drive mode.
    Updated CLAUDE.md pin assignments to match current wiring:
    Motors: IN1=GPIO17, IN2=GPIO22, IN3=GPIO5, IN4=GPIO6
    Sensor: TRIG=GPIO23, ECHO=GPIO24
    [GPIO_Current.csv]
2026-03-21 Update shell, elktron app, assembly, labels, and progress
    Adds final shell design iterations (shell.scad, Final_shell.scad, shell_draft.scad),
    updated STL export, label fixes to match wiring guide, elktron app additions,
    and assembly page updates.
    [Final_shell.scad, shell.stl, shell_draft.scad]
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2026-03-23 Merge Stitch UI screens into Elktron dashboard
    Replace utilitarian dashboard with polished Stitch-designed tabbed UI:
    - Boot splash overlay with animated progress bar
    - 4 tabs: Dashboard, Camera Feed, Navigation, Diagnostics
    - Material Design 3 dark theme (Tailwind + Space Grotesk)
    - Sidebar nav with Emergency Stop
    - All JS ported: WebSocket, teleop, YOLO/follow toggles
    - Added ui/ folder with 8 original Stitch screen exports
    - Backup of previous dashboard in index.html.bak
